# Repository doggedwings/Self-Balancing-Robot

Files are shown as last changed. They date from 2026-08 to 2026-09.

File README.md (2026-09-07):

# Self-Balancing Robot

A two wheeled robot that keeps itself upright with a PID controller running on an ESP32. Two NEMA 17 steppers, an MPU6050 for tilt, and a 3D printed chassis. You drive it from a web page over WiFi.

# WATCH IT BALANCE HERE <your video link here>

# Why I Built This

I wanted something I could drive around, and a normal RC car felt like the obvious version of that. A robot that has to actively work to not fall over just sitting still seemed like a better problem.

The other half was that I wanted to challenge myself with a PID loop. This one couldn't be cheated. I had to manually tune it and actually learn how the controls worked, or it just fell over.

It still drives like an RC car. It just has to solve a much harder problem to do it.

# How It Works

The MPU6050 reports the chassis tilt angle and angular rate. The ESP32 runs a cascaded PID loop that converts that tilt into a motor acceleration command, and the two steppers drive the wheels underneath the centre of mass to keep it from falling. 
Since it can only stay upright by continuously moving, driving it is a matter of lying to the controller: commanding a small target tilt makes it chase itself forward, and a speed differential between the two wheels turns it. An Xbox controller sends those commands over Bluetooth.

# Hardware Specs

The Brain: ESP32, balance loop and Bluetooth stack pinned to separate cores 
The Motors: 2x NEMA 17 stepper motors
The Drivers: 2x A4988 stepper drivers, microstepped, STEP pulses generated by hardware timers
The Inner Ear: MPU6050 6-axis IMU (accelerometer + gyroscope) over I2C 
Power: 8x AA pack (12 V) for motors, buck converter to 5 V for ESP32 logic, separate breadboard rails
Control: Xbox controller over Bluetooth OR phone app 
Chassis & Wheels: Custom 3D printed, Fusion 360 designed printed in PETG

# Engineering

1. Two PID Loops Instead of One

A single PID on tilt angle keeps the robot upright but lets it slowly roll across the room, since nothing in the loop cares about position. The fix was nesting two loops: an outer loop reads wheel speed and outputs a target lean angle, and an inner loop drives motor acceleration to hit that angle. The outer loop runs at a quarter the rate of the inner one so the two don't fight each other. Driving works by lying to the controller, since asking for a small lean makes the balance loop chase it forward. Final gains were Kp 40, Ki 0.5, Kd 2.4 with a 2.8 degree trim to correct for how the IMU sits on the frame.

2. Floating Point Crashed the Step Interrupt

Step pulses are generated by a hardware timer interrupt at 20 kHz, and the first version panicked with a LoadProhibited exception the instant that timer fired. The ESP32 doesn't save its floating point registers when entering an interrupt, so any float math inside a handler faults immediately, and the motor speed variables were floats. Converting them to integers before they reach the interrupt fixed it, since the float math still happens in normal task context where it's safe. The same handler also writes GPIO registers directly instead of calling digitalWrite, which lives in flash and isn't guaranteed to be loaded when an interrupt fires.

3. Full Step Was Shaking the Sensor

At full step the motors move in 1.8 degree jolts, and that vibration travels through the frame straight into the MPU6050. The accelerometer can't distinguish motor cogging from real tilt, so the noise entered the control loop and came back out as more motor commands, producing a jitter that no amount of tuning removed. Switching the A4988s to 1/8 microstepping smoothed the motion out and eliminated most of it. Every gain had to be rescaled by 8x afterwards, since each step now moves the robot an eighth as far.

4. Power Was Half the Problem

Motors and logic run on separate breadboard rails, because steppers pull enough current in bursts to sag a shared rail, and a sagging rail resets the ESP32 mid correction in a way that looks exactly like a firmware bug. Two failures cost real hardware along the way. One A4988 failed internally and shorted RESET to ground, which pulled the 3.3V rail down through the ESP32's onboard regulator until it cooked. And the 8x AA pack reads 11.8V with nothing attached but collapses to 2V the moment the motors draw current once the cells are spent, so open circuit voltage tells you nothing about whether a pack is still good.

# Schematic

# CAD

# Roadmap for version 2

Custom PCB replacing the breadboard. A 2 layer board carrying the ESP32, both A4988s, the IMU, and separate regulation for each rail. Breadboard contact resistance and jumpers working loose are the biggest source of unexplained behaviour right now.

Xbox controller over Bluetooth instead of the web page, for lower latency and analog stick control.

Aesthetics. Enclosed printed shell, hidden wiring, proper face panel.

IMU upgrade to a BNO055, which does sensor fusion onboard instead of filtering raw MPU6050 output in firmware.

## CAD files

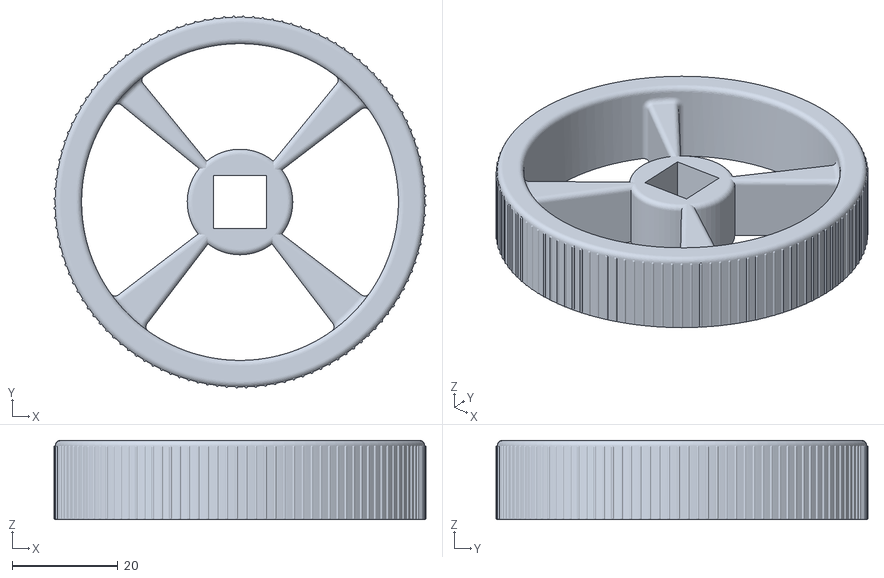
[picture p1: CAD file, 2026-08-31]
CAD Files/Wheel.stl
70.5 x 70.5 x 15.0

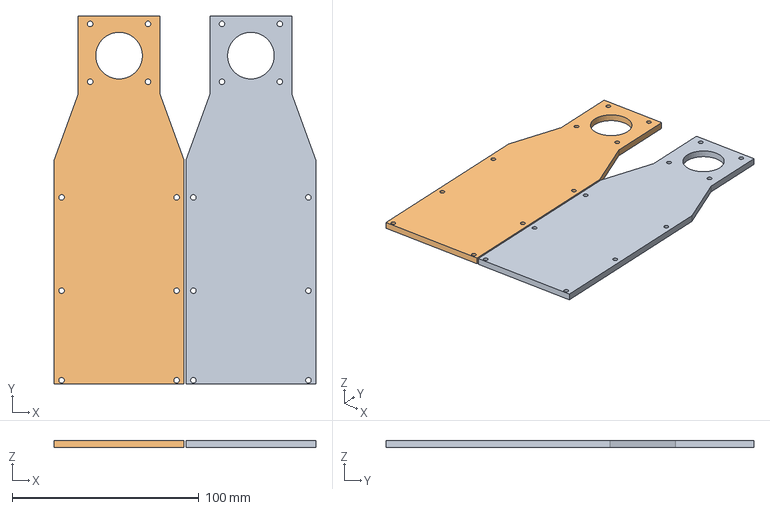
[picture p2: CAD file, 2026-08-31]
CAD Files/Side Plate and Motor Mount.3mf
140.3 x 197.2 x 4.00 mm
PLATE.stl x 2

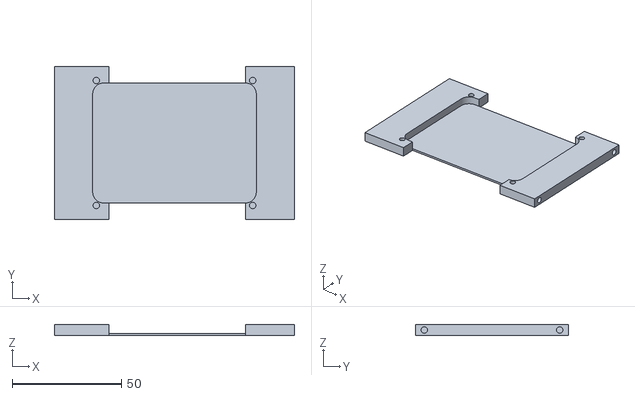
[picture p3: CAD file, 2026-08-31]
CAD Files/ESP32 Level.stl
110.0 x 70.0 x 5.00

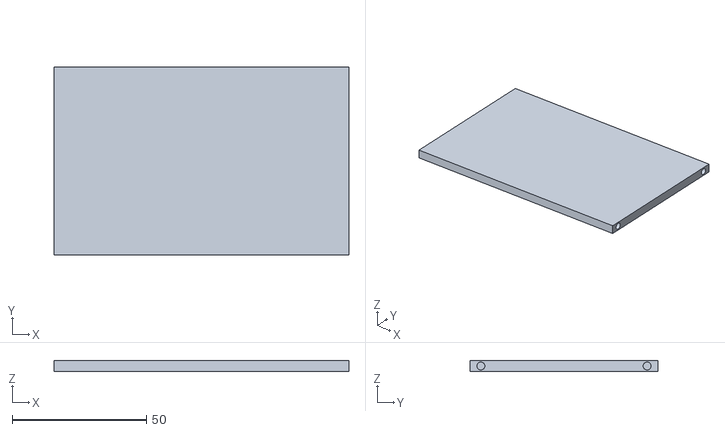
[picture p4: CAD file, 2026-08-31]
CAD Files/Top Level.stl
110.0 x 70.0 x 4.00

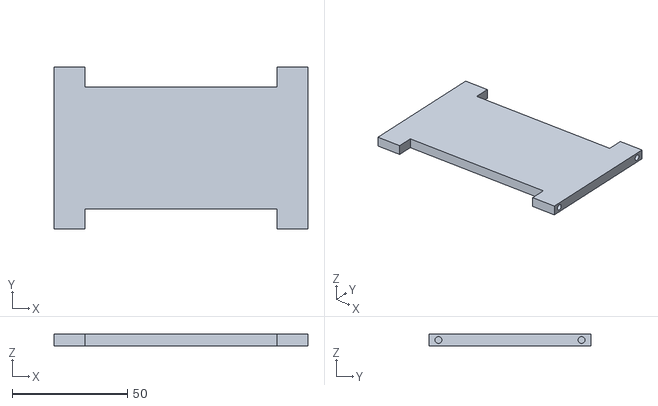
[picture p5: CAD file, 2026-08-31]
CAD Files/Breadboard Level.stl
110.0 x 70.0 x 5.00

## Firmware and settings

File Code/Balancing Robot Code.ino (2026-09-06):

/*
  BalanceBot — ESP32 self-balancing robot

  Pin map:
    GPIO 32  Driver 1 STEP        GPIO 33  Driver 1 DIR
    GPIO 26  Driver 2 STEP        GPIO 27  Driver 2 DIR
    GPIO 25  Both EN (active low, 10k pull-up to 3.3V)
    GPIO 19  MPU6050 SDA          GPIO 18  MPU6050 SCL

  1/8 microstepping: MS1 high, MS2 high, MS3 low = 1600 steps/rev.
  WiFi AP "BalanceBot" / pass "balancebot" -> http://192.168.4.1

  Gains persist across reboots (saved to flash on every Apply).
  Gains can also be set from the address bar, e.g.
    http://192.168.4.1/gains?kpa=40&kda=1.6&trim=3

  Adjust number on line 382 to increase or decrease max speed.
*/

#include <WiFi.h>
#include <WebServer.h>
#include <Wire.h>
#include <Preferences.h>
#include "soc/gpio_reg.h"

#define M1_STEP 32
#define M1_DIR  33
#define M2_STEP 26
#define M2_DIR  27
#define MOT_EN  25
#define I2C_SDA 19
#define I2C_SCL 18

#define M1_INVERT  false
#define M2_INVERT  true

#define STEPS_PER_REV   1600.0f
#define MAX_SPEED       6000.0f
#define MAX_ACCEL       96000.0f
#define FALL_ANGLE      40.0f
#define LOOP_HZ         100.0f
#define SPEED_LOOP_DIV  4
#define ISR_HZ          20000
#define CMD_TIMEOUT_MS  1000

volatile float Kp_angle = 40.0f;
volatile float Ki_angle = 0.5f;
volatile float Kd_angle = 2.4f;
volatile float Kp_speed = 0.002f;
volatile float Ki_speed = 0.004f;
volatile float angleTrim = 2.8f;

volatile float  motor1Speed = 0, motor2Speed = 0;
volatile bool   motorsEnabled = false;
volatile uint32_t lastCmdMs = 0;

float pitch = 0, gyroRate = 0;
float gyroBiasY = 0;
float angleIntegral = 0, speedIntegral = 0;
float targetAngle = 0;
float cmdSpeed = 0, cmdTurn = 0;
float cmdSpeedSmooth = 0, cmdTurnSmooth = 0;
bool  fallen = true;
uint32_t lastLoopUs = 0;
uint8_t speedLoopCounter = 0;

Preferences prefs;

hw_timer_t *stepTimer = NULL;
portMUX_TYPE stepMux = portMUX_INITIALIZER_UNLOCKED;
volatile int32_t acc1 = 0, acc2 = 0;
volatile int32_t isrSpeed1 = 0, isrSpeed2 = 0;

// IRAM-safe GPIO write. Handles both banks (pins above 31 use OUT1 registers).
static inline void IRAM_ATTR fastWrite(uint8_t pin, bool level) {
  if (pin < 32) {
    REG_WRITE(level ? GPIO_OUT_W1TS_REG : GPIO_OUT_W1TC_REG, 1UL << pin);
  } else {
    REG_WRITE(level ? GPIO_OUT1_W1TS_REG : GPIO_OUT1_W1TC_REG, 1UL << (pin - 32));
  }
}

void IRAM_ATTR onStepTimer() {
  fastWrite(M1_STEP, false);
  fastWrite(M2_STEP, false);

  int32_t s1 = isrSpeed1;
  if (s1 != 0) {
    fastWrite(M1_DIR, ((s1 > 0) != M1_INVERT));
    acc1 += (s1 > 0 ? s1 : -s1);
    if (acc1 >= ISR_HZ) { acc1 -= ISR_HZ; fastWrite(M1_STEP, true); }
  }

  int32_t s2 = isrSpeed2;
  if (s2 != 0) {
    fastWrite(M2_DIR, ((s2 > 0) != M2_INVERT));
    acc2 += (s2 > 0 ? s2 : -s2);
    if (acc2 >= ISR_HZ) { acc2 -= ISR_HZ; fastWrite(M2_STEP, true); }
  }
}

void setMotorSpeeds(float s1, float s2) {
  portENTER_CRITICAL(&stepMux);
  isrSpeed1 = (int32_t)s1;
  isrSpeed2 = (int32_t)s2;
  portEXIT_CRITICAL(&stepMux);
}

void loadGains() {
  prefs.begin("bot", true);
  Kp_angle  = prefs.getFloat("kpa", 40.0f);
  Ki_angle  = prefs.getFloat("kia", 0.0f);
  Kd_angle  = prefs.getFloat("kda", 1.6f);
  Kp_speed  = prefs.getFloat("kps", 0.0f);
  Ki_speed  = prefs.getFloat("kis", 0.0f);
  angleTrim = prefs.getFloat("trim", 3.0f);
  prefs.end();
}

void saveGains() {
  prefs.begin("bot", false);
  prefs.putFloat("kpa", Kp_angle);
  prefs.putFloat("kia", Ki_angle);
  prefs.putFloat("kda", Kd_angle);
  prefs.putFloat("kps", Kp_speed);
  prefs.putFloat("kis", Ki_speed);
  prefs.putFloat("trim", angleTrim);
  prefs.end();
}

#define MPU_ADDR 0x68

bool mpuWrite(uint8_t reg, uint8_t val) {
  Wire.beginTransmission(MPU_ADDR);
  Wire.write(reg);
  Wire.write(val);
  return Wire.endTransmission() == 0;
}

bool mpuInit() {
  Wire.begin(I2C_SDA, I2C_SCL, 100000);
  Wire.setTimeOut(50);
  delay(50);
  Wire.beginTransmission(MPU_ADDR);
  if (Wire.endTransmission() != 0) return false;
  mpuWrite(0x6B, 0x80); delay(100);
  mpuWrite(0x6B, 0x01); delay(50);
  mpuWrite(0x1A, 0x03);
  mpuWrite(0x1B, 0x00);
  mpuWrite(0x1C, 0x00);
  delay(50);
  return true;
}

void mpuRead(float &ax, float &ay, float &az, float &gy) {
  Wire.beginTransmission(MPU_ADDR);
  Wire.write(0x3B);
  Wire.endTransmission(false);
  Wire.requestFrom(MPU_ADDR, 14, true);
  if (Wire.available() < 14) { ax = ay = az = gy = 0; return; }
  int16_t rax = (Wire.read() << 8) | Wire.read();
  int16_t ray = (Wire.read() << 8) | Wire.read();
  int16_t raz = (Wire.read() << 8) | Wire.read();
  Wire.read(); Wire.read();
  Wire.read(); Wire.read();
  int16_t rgy = (Wire.read() << 8) | Wire.read();
  Wire.read(); Wire.read();
  ax = rax / 16384.0f;
  ay = ray / 16384.0f;
  az = raz / 16384.0f;
  gy = rgy / 131.0f;
}

void calibrateGyro() {
  float sum = 0;
  int good = 0;
  for (int i = 0; i < 500; i++) {
    float ax, ay, az, gy;
    mpuRead(ax, ay, az, gy);
    if (!(ax == 0 && ay == 0 && az == 0)) { sum += gy; good++; }
    delay(3);
  }
  Serial.printf("  %d/500 reads ok\n", good);
  gyroBiasY = good ? sum / good : 0;
}

float accelPitch(float ax, float ay, float az) {
  return atan2f(-ax, az) * 57.2957795f;
}

WebServer server(80);

const char PAGE[] PROGMEM = R"HTML(<!DOCTYPE html><html><head>
<meta name=viewport content="width=device-width,initial-scale=1">
<title>BalanceBot</title><style>
body{font-family:system-ui,sans-serif;background:#15171a;color:#e6e6e6;margin:0;padding:16px}
h2{font-weight:500;margin:0 0 12px}
.row{display:flex;gap:8px;align-items:center;margin:6px 0}
.row label{width:110px;font-size:13px;color:#9aa0a6}
input[type=number]{width:80px;background:#22262b;border:1px solid #3a3f45;color:#e6e6e6;padding:5px;border-radius:5px}
button{background:#2d6cdf;border:0;color:#fff;padding:9px 16px;border-radius:6px;font-size:14px;cursor:pointer}
button.stop{background:#c0392b}
#tel{font-family:ui-monospace,monospace;font-size:13px;background:#1b1e22;padding:10px;border-radius:6px;line-height:1.7;white-space:pre}
#st{font-size:12px;color:#7d8590;margin:4px 0 0}
.keys{display:grid;grid-template-columns:repeat(3,54px);gap:6px;margin:14px 0}
.k{height:46px;background:#22262b;border:1px solid #3a3f45;border-radius:6px;display:flex;align-items:center;justify-content:center;font-size:15px;user-select:none;touch-action:none}
.k.on{background:#2d6cdf;border-color:#2d6cdf}
.sp{visibility:hidden}
small{color:#7d8590}
</style></head><body>
<h2>BalanceBot</h2>
<div id=tel>connecting...</div>
<div class=keys>
<div class="k sp"></div><div class=k id=kW>W</div><div class="k sp"></div>
<div class=k id=kA>A</div><div class=k id=kS>S</div><div class=k id=kD>D</div>
</div>
<div class=row><button id=en>Enable</button><button class=stop id=stop>STOP (space)</button></div>
<div class=row><label>Kp angle</label><input type=number step=0.5 id=kpa></div>
<div class=row><label>Ki angle</label><input type=number step=0.1 id=kia></div>
<div class=row><label>Kd angle</label><input type=number step=0.05 id=kda></div>
<div class=row><label>Kp speed</label><input type=number step=0.005 id=kps></div>
<div class=row><label>Ki speed</label><input type=number step=0.005 id=kis></div>
<div class=row><label>Angle trim</label><input type=number step=0.2 id=trim></div>
<div class=row><button id=apply>Apply and save</button></div>
<div id=st>fields sync with the robot until you edit one</div>
<small>Hold keys to drive. Gains are saved to flash on Apply.</small>
<script>
let held={w:0,a:0,s:0,d:0},dirty=false,touched=false;
const ids=['kpa','kia','kda','kps','kis','trim'];
const map={KeyW:'w',KeyA:'a',KeyS:'s',KeyD:'d',ArrowUp:'w',ArrowLeft:'a',ArrowDown:'s',ArrowRight:'d'};
function paint(){for(const k of['w','a','s','d'])document.getElementById('k'+k.toUpperCase()).classList.toggle('on',!!held[k]);}
for(const id of ids)document.getElementById(id).addEventListener('input',()=>{
 touched=true;document.getElementById('st').textContent='edited - press Apply to send';});
addEventListener('keydown',e=>{if(e.target.tagName==='INPUT')return;
 if(e.code==='Space'){estop();e.preventDefault();return;}
 const k=map[e.code];if(k&&!held[k]){held[k]=1;dirty=true;paint();e.preventDefault();}});
addEventListener('keyup',e=>{if(e.target.tagName==='INPUT')return;
 const k=map[e.code];if(k){held[k]=0;dirty=true;paint();e.preventDefault();}});
addEventListener('blur',()=>{held={w:0,a:0,s:0,d:0};dirty=true;paint();});
for(const k of ['w','a','s','d']){const el=document.getElementById('k'+k.toUpperCase());
 const on=e=>{held[k]=1;dirty=true;paint();e.preventDefault();};
 const off=e=>{held[k]=0;dirty=true;paint();e.preventDefault();};
 el.addEventListener('pointerdown',on);el.addEventListener('pointerup',off);el.addEventListener('pointerleave',off);}
function estop(){fetch('/stop');held={w:0,a:0,s:0,d:0};paint();}
document.getElementById('stop').onclick=estop;
document.getElementById('en').onclick=()=>fetch('/enable');
document.getElementById('apply').onclick=()=>{
 const q=ids.map(i=>i+'='+document.getElementById(i).value).join('&');
 document.getElementById('st').textContent='sending...';
 fetch('/gains?'+q).then(()=>{touched=false;
  document.getElementById('st').textContent='applied and saved';})
 .catch(()=>{document.getElementById('st').textContent='send FAILED - retry';});};
setInterval(()=>{fetch(`/c?f=${held.w-held.s}&t=${held.d-held.a}`);},150);
setInterval(async()=>{try{const r=await fetch('/t');const d=await r.json();
 document.getElementById('tel').textContent=
  `angle  ${d.a.toFixed(2)} deg\ntarget ${d.g.toFixed(2)} deg\nspeed  ${d.s.toFixed(0)} steps/s\nstate  ${d.e?(d.f?'FALLEN':'RUNNING'):'DISABLED'}`;
 if(!touched){kpa.value=d.p1;kia.value=d.i1;kda.value=d.d1;kps.value=d.p2;kis.value=d.i2;trim.value=d.tr;}
 }catch(e){}},200);
</script></body></html>)HTML";

void handleRoot()  { server.send_P(200, "text/html", PAGE); }

void handleCmd() {
  cmdSpeed = server.arg("f").toFloat();
  cmdTurn  = server.arg("t").toFloat();
  lastCmdMs = millis();
  server.send(200, "text/plain", "ok");
}

void handleStop() {
  motorsEnabled = false;
  cmdSpeed = cmdTurn = 0;
  server.send(200, "text/plain", "stopped");
}

void handleEnable() {
  angleIntegral = speedIntegral = 0;
  lastCmdMs = millis();
  motorsEnabled = true;
  server.send(200, "text/plain", "enabled");
}

void handleGains() {
  if (server.hasArg("kpa"))  Kp_angle  = server.arg("kpa").toFloat();
  if (server.hasArg("kia"))  Ki_angle  = server.arg("kia").toFloat();
  if (server.hasArg("kda"))  Kd_angle  = server.arg("kda").toFloat();
  if (server.hasArg("kps"))  Kp_speed  = server.arg("kps").toFloat();
  if (server.hasArg("kis"))  Ki_speed  = server.arg("kis").toFloat();
  if (server.hasArg("trim")) angleTrim = server.arg("trim").toFloat();
  angleIntegral = speedIntegral = 0;
  saveGains();
  Serial.printf("gains: Kp %.2f  Ki %.2f  Kd %.2f  kps %.3f  kis %.3f  trim %.1f\n",
                Kp_angle, Ki_angle, Kd_angle, Kp_speed, Ki_speed, angleTrim);
  server.send(200, "text/plain", "ok");
}

void handleTelemetry() {
  lastCmdMs = millis();
  char buf[220];
  snprintf(buf, sizeof(buf),
    "{\"a\":%.2f,\"g\":%.2f,\"s\":%.0f,\"e\":%d,\"f\":%d,"
    "\"p1\":%.2f,\"i1\":%.2f,\"d1\":%.2f,\"p2\":%.3f,\"i2\":%.3f,\"tr\":%.1f}",
    pitch, targetAngle, motor1Speed, motorsEnabled ? 1 : 0, fallen ? 1 : 0,
    Kp_angle, Ki_angle, Kd_angle, Kp_speed, Ki_speed, angleTrim);
  server.send(200, "application/json", buf);
}

void balanceTask(void *param) {
  lastLoopUs = micros();
  for (;;) {
    uint32_t now = micros();
    float dt = (now - lastLoopUs) / 1000000.0f;
    if (dt < 1.0f / LOOP_HZ) { vTaskDelay(1); continue; }
    lastLoopUs = now;
    if (dt > 0.05f) dt = 0.05f;

    float ax, ay, az, gy;
    mpuRead(ax, ay, az, gy);
    gyroRate = gy - gyroBiasY;

    float accAngle = accelPitch(ax, ay, az);
    pitch = 0.98f * (pitch + gyroRate * dt) + 0.02f * accAngle;

    if (fabsf(pitch - angleTrim) > FALL_ANGLE) {
      if (!fallen) { angleIntegral = speedIntegral = 0; }
      fallen = true;
      motor1Speed = motor2Speed = 0;
      setMotorSpeeds(0, 0);
      digitalWrite(MOT_EN, HIGH);
      vTaskDelay(1);
      continue;
    }
    if (fallen && fabsf(pitch - angleTrim) < 3.0f) fallen = false;

    if (!motorsEnabled || fallen) {
      motor1Speed = motor2Speed = 0;
      setMotorSpeeds(0, 0);
      digitalWrite(MOT_EN, HIGH);
      vTaskDelay(1);
      continue;
    }
    digitalWrite(MOT_EN, LOW);

    // If the browser goes away, stop driving but keep balancing.
    if (millis() - lastCmdMs > CMD_TIMEOUT_MS) { cmdSpeed = 0; cmdTurn = 0; }

    cmdSpeedSmooth += (cmdSpeed - cmdSpeedSmooth) * 0.05f;
    cmdTurnSmooth  += (cmdTurn  - cmdTurnSmooth)  * 0.05f;

    if (++speedLoopCounter >= SPEED_LOOP_DIV) {
      speedLoopCounter = 0;
      float actualSpeed = (motor1Speed + motor2Speed) * 0.5f;
      float wantSpeed   = cmdSpeedSmooth * MAX_SPEED * 0.20f;
      float sErr = wantSpeed - actualSpeed;
      if (Ki_speed == 0.0f) {
        speedIntegral = 0;
      } else {
        speedIntegral += sErr * (dt * SPEED_LOOP_DIV);
        speedIntegral = constrain(speedIntegral, -3000.0f, 3000.0f);
      }
      targetAngle = Kp_speed * sErr + Ki_speed * speedIntegral;
      targetAngle = constrain(targetAngle, -12.0f, 12.0f);
      targetAngle = -targetAngle + angleTrim;
    }

    float aErr = targetAngle - pitch;
    if (Ki_angle == 0.0f) {
      angleIntegral = 0;
    } else {
      angleIntegral += aErr * dt;
      angleIntegral = constrain(angleIntegral, -200.0f, 200.0f);
    }

    float dTerm = -gyroRate;
    float accel = Kp_angle * aErr + Ki_angle * angleIntegral + Kd_angle * dTerm;
    accel = constrain(accel, -MAX_ACCEL * dt, MAX_ACCEL * dt);

    float base = (motor1Speed + motor2Speed) * 0.5f + accel;
    base = constrain(base, -MAX_SPEED, MAX_SPEED);

    float turn = cmdTurnSmooth * MAX_SPEED * 0.15f;
    motor1Speed = constrain(base + turn, -MAX_SPEED, MAX_SPEED);
    motor2Speed = constrain(base - turn, -MAX_SPEED, MAX_SPEED);

    setMotorSpeeds(motor1Speed, motor2Speed);
    vTaskDelay(1);
  }
}

void setup() {
  Serial.begin(115200);
  delay(300);

  pinMode(M1_STEP, OUTPUT); pinMode(M1_DIR, OUTPUT);
  pinMode(M2_STEP, OUTPUT); pinMode(M2_DIR, OUTPUT);
  pinMode(MOT_EN,  OUTPUT);
  digitalWrite(MOT_EN, HIGH);
  digitalWrite(M1_STEP, LOW); digitalWrite(M2_STEP, LOW);

  Serial.println("\nBalanceBot starting");

  loadGains();
  Serial.printf("gains: Kp %.2f  Ki %.2f  Kd %.2f  kps %.3f  kis %.3f  trim %.1f\n",
                Kp_angle, Ki_angle, Kd_angle, Kp_speed, Ki_speed, angleTrim);

  if (!mpuInit()) {
    Serial.println("MPU6050 NOT FOUND on GPIO19/18 - check wiring, halting");
    while (1) { delay(1000); }
  }
  Serial.println("MPU6050 ok. Hold the robot STILL and upright...");
  delay(1500);
  calibrateGyro();
  Serial.printf("gyro bias Y = %.3f dps\n", gyroBiasY);

  { float ax, ay, az, gy; mpuRead(ax, ay, az, gy); pitch = accelPitch(ax, ay, az); }
  Serial.printf("starting pitch = %.2f deg\n", pitch);

  Serial.printf("Arduino core %d.%d.%d\n",
                ESP_ARDUINO_VERSION_MAJOR, ESP_ARDUINO_VERSION_MINOR,
                ESP_ARDUINO_VERSION_PATCH);

#if ESP_ARDUINO_VERSION_MAJOR >= 3
  stepTimer = timerBegin(1000000);
  if (!stepTimer) { Serial.println("timerBegin FAILED"); while (1) delay(1000); }
  timerAttachInterrupt(stepTimer, &onStepTimer);
  timerAlarm(stepTimer, 1000000 / ISR_HZ, true, 0);
#else
  stepTimer = timerBegin(0, 80, true);
  if (!stepTimer) { Serial.println("timerBegin FAILED"); while (1) delay(1000); }
  timerAttachInterrupt(stepTimer, &onStepTimer, true);
  timerAlarmWrite(stepTimer, 1000000 / ISR_HZ, true);
  timerAlarmEnable(stepTimer);
#endif

  Serial.println("timer ok");

  WiFi.mode(WIFI_AP);
  WiFi.softAP("BalanceBot", "balancebot");
  Serial.print("AP up at http://");
  Serial.println(WiFi.softAPIP());

  server.on("/",       handleRoot);
  server.on("/c",      handleCmd);
  server.on("/t",      handleTelemetry);
  server.on("/stop",   handleStop);
  server.on("/enable", handleEnable);
  server.on("/gains",  handleGains);
  server.begin();

  lastCmdMs = millis();
  xTaskCreatePinnedToCore(balanceTask, "balance", 8192, NULL, 5, NULL, 1);

  Serial.println("ready - open the page and press Enable");
}

void loop() {
  server.handleClient();
  delay(1);
}
